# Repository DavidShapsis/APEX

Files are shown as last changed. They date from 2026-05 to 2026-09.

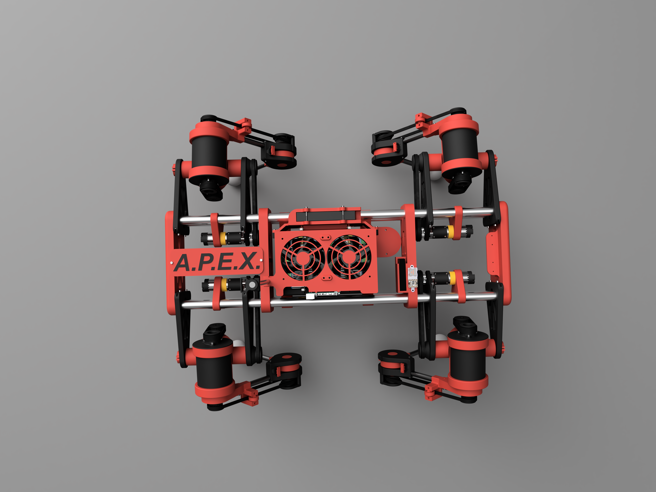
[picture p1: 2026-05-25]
Photos/APEX_top_view.png

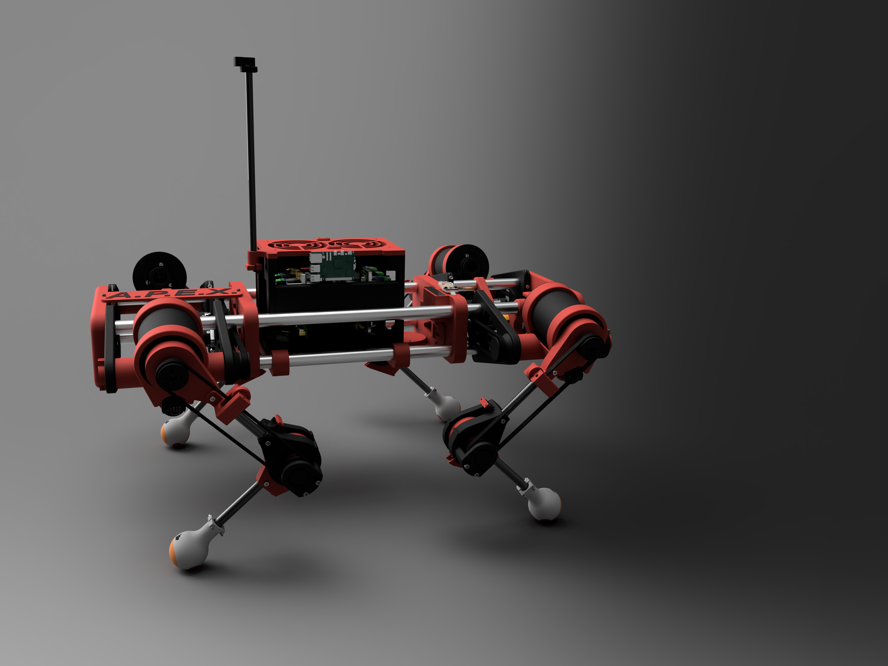
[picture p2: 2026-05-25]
Photos/APEX_side_view.png

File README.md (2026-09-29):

 **⚠️ This is an ongoing project. The code, CAD, and documentation are all actively being developed and are not final.**
 
---
 
# APEX — Autonomous Precision Exploration
 
A fully custom-built quadruped robot dog designed and coded from scratch.

APEX is designed to walk across varied outdoor terrain using real-time inverse kinematics, stay balanced using an IMU, navigate to GPS waypoints autonomously, and stream live camera footage back to any device over WiFi. The long-term goal is onboard ML-based obstacle avoidance for fully autonomous terrain exploration.
 




 
---
 
## Features
 
- **Inverse Kinematics** — custom 3-link IK engine with forward kinematics for recovery, computing joint angles in real time for all four legs
- **Body-Twist Steering** — each foot arcs about the body centre so the robot yaws in place or blends yaw with forward travel into an arc, recruiting the hip-roll joint into the turn (not tank-style stride differencing)
- **IMU Stabilization** — BNO085 quaternion-based roll/pitch feeds a per-leg differential foot-height correction, so the body actually levels instead of just translating
- **GPS Navigation** — autonomous waypoint following using bearing and distance calculations from a HGLRC M100 GPS module; the route is entered and reordered live from the dashboard, and the robot holds position (marching in place) once the last point is reached
- **Live Video Streaming** — USB webcam feed served over Flask to any device on the same network
- **Mission Control Dashboard** — Flask web UI that walks through homing each leg, standing, and going before the robot is allowed to walk; live camera feed with a steering readout, an obstacle-avoidance toggle, and per-leg debug controls. Served entirely from the Pi (Bootstrap vendored locally, no internet needed in the field)
- **ML Obstacle Avoidance** — pretrained monocular depth model (Depth-Anything-V2-Small, ONNX) turns the webcam feed into a forward costmap and steers around obstacles, layered on top of both manual and GPS waypoint steering. Dashboard toggle
- **Threaded Sensor Polling** — every blocking sensor read (IMU + compass over I2C, GPS UART, INA219) runs on its own poller thread; the control loop only ever reads a lock-protected snapshot, so a stuck bus degrades to a safe default instead of stalling the gait
- **Per-Motor Current Sensing** *(planned, not started)* — reading each BTS7960's built-in `IS` output so a joint meeting unexpected resistance (a crash, a jam) drops the robot into its recovery routine, replacing the FSR-based foot contact. No code for this exists yet; see `ENGINEERING_NOTES.md`
- **ROS 2 Integration** — inter-node communication via ROS 2 topics for direction commands, navigation mode switching, and the homing/stand/go/stop dashboard controls

---
 
## BOM
 
| Component | Qty | Notes |
|---|---|---|
| Raspberry Pi 5 | 1 | Main brain |
| Raspberry Pi Pico (RP2040) | 4 | One per leg, runs MicroPython |
| GoBilda 5302 Yellow Jacket Motor (99.5:1, 60 RPM) | 12 | 3 per leg |
| BTS7960 43A H-Bridge | 12 | One per joint |
| BNO085 IMU | 1 | Quaternion-based orientation |
| HGLRC M100-5883 GPS/Compass | 1 | Outdoor autonomous nav |
| INA219 Voltage Monitor | 1 | Battery voltage; current sensing wired but unconfirmed/unused, see `ENGINEERING_NOTES.md` |
| Carbon Fiber Tube (16x12mm) | — | Lower leg structure |
| Aluminum 6063 Tube (1in OD) | — | Upper leg structure |
| 3S 11.1V LiPo 80C 5Ah | 1 | Motor power |
| 2S 7.6V LiHV 3.5Ah | 1 | Electronics power |
| Custom PCB | 1 | High-current motor control, in progress |
 *BOM subject to change. For the most recent BOM go to [APEX BOM on Google Sheets](https://docs.google.com/spreadsheets/d/1m-T2-i6hj74-5jb7eDYWLMdHvXfgs2ABYw7gbwLl6ZI/edit?usp=sharing)*
---
 
## Software Architecture
 
```
Pi 5 (ROS 2)
├── pi5_main.py          # Main control loop, gait generation, homing/stand/go/stop state
├── inverse_kinematics/
│   ├── ik_and_gait.py   # IK, FK, GaitPath, GaitIK, RecoveryPath, shared leg/body geometry
│   └── quadruped_sim.py # PC-only 4-leg gait simulator (no ROS) -- --report and 3D animation modes
├── sensor_hub.py        # Per-sensor poller threads -- keeps blocking I2C/UART off the control loop
├── boot_display.py      # Optional SH1106 OLED: boot progress + status (no-op if absent)
├── imu.py               # BNO085 quaternion → roll/pitch
├── navigation.py        # GPS parsing, compass, waypoint navigation
├── stream_server.py     # Flask dashboard node -- ROS wiring, routes, /status plumbing
├── dashboard_page.py    # The dashboard HTML/CSS/JS (shared string, zero deps)
├── dashboard_preview.py # Throwaway standalone dashboard mock (Flask only, no hardware)
├── static/              # Vendored assets served at /static/ (bootstrap.min.css)
├── webcam.py            # USB camera capture
├── vision_obstacle.py   # Depth model, obstacle costmap, committed avoidance planner
├── vision_test/         # Standalone notebook for tuning the vision pipeline
├── power_monitor.py     # INA219 -- voltage only is read; current/power path unconfirmed, see ENGINEERING_NOTES
├── audio.py             # Bluetooth speaker alerts
├── requirements.txt     # pip dependencies (ROS 2 itself is a separate apt install)
└── single_leg_test.py   # Standalone single-leg test harness (no ROS/IMU/GPS)
 
Pico (MicroPython, x4)
├── pico_main.py         # UART receiver, gait buffer, PID execution loop, homing/stop commands
├── motor_control.py     # BTS7960 PID joint controller with encoder feedback
└── fsr.py               # Force sensitive resistor foot contact (set FSR_PIN per leg)
```
 
### Pi to Pico Protocol
 
The Pi sends gait data over UART to each Pico using a binary protocol:
 
- **Start:** `0xAA 0xAA`
- **Home leg:** `0xAB 0xAB` -- zero this leg's encoders to the current physical pose, no payload
- **Stop leg:** `0xAC 0xAC` -- cut motor holding torque, keep encoder tracking, no payload
- **Payload:** up to 20 steps (gait) or 40 (ramp) x 16 bytes each (`struct.pack('ffff', roll, pitch, knee, is_swing)`)
- **End (cycle):** `0xFF × 16` -- Pico loops the buffer indefinitely (the walking gait)
- **End (one-shot):** `0xFE × 16` -- Pico holds the final step (startup/recovery ramps)
 
Each Pico steps through the gait buffer at 40ms per step. It's a **crawl gait, one leg airborne at a time** (25% swing / 75% stance duty factor) rather than a trot -- the four legs are phase-offset by `[0, N/2, 3N/4, N/4]`, giving lift order FL → RR → FR → RL, with three feet always planted. Each Pico also announces `LEG,<id>` over UART until it's identified, and reports `HOMED,<id>` / `ABORTED,<angles>` asynchronously.
 
---
 
## Kinematics
 
The IK engine uses a 3-link chain (hip abductor, thigh, shin) solving for roll, pitch, and knee angles given a target foot position in (X, Y, Z):
 
1. **Roll** — solved in the X-Z plane using `atan2` + `acos` geometry on the abductor link
2. **Pitch/Knee** — solved in the virtual leg plane using law of cosines
Forward kinematics is used for the recovery path, reconstructing foot position from joint angles to interpolate back to home stance.
 
Segment lengths (cm): `a = 9.65` (abductor), `b = 26.84` (thigh), `c = 24.37` (shin)
 
---
 
## Gait
 
The gait path is a 20-step cycle, one leg airborne at a time (25% of the cycle) so three feet are always planted:
 
- **Swing phase** (first 25% of the cycle): a true half-ellipse -- the foot sweeps forward and up together as matched cos/sin of the same angle, easing into liftoff and touchdown instead of slamming into them
- **Stance phase** (remaining 75%): the foot travels backward at constant velocity (deliberately linear, not elliptical, so all three planted feet move at the same rate and don't scrub against the ground)
- **Body shift**: the body leans toward the diagonally-opposite hip just before each lift, to keep the centre of mass off the edge of the support triangle (ramped from 2 cm to 4 cm as a turn tightens)
- **IMU levelling**: differential per-leg foot-height correction from roll/pitch, not a common offset
 
### Steering
 
A **body twist**, not stride differencing. `build_gait()` takes a forward stride and a yaw-per-cycle; each planted foot arcs about the body centre (`body_twist_xy_path`), its neutral hip position rotated `± yaw/2` across the stroke, so the four feet phased together rotate the body -- the hip-roll joint carrying the lateral part of each arc. `yaw == 0` is the straight gait, unchanged term for term.
 
`pi5_main` maps the turn command (+ = right; a dashboard control or the GPS heading error) to a yaw rate plus a forward stride that tapers to zero by 90°, so a ±90° command spins in place while a smaller heading error arcs and still advances. On the dashboard the **LEFT / RIGHT** buttons send ±45° (a moderate arc at about half stride) and the slider spans the full −90°…+90°, its ends being a spin in place; the slider tracks the buttons so it always shows the active command. `quadruped_sim.py --report` checks the straight gait *and* a turn sweep: a full spin is ~13°/cycle (~16°/s, a 90° turn in ~5.5 s) with the stability margin, joint rate, and one-leg-airborne crawl all holding.
 
Before any of this runs, the robot must be homed, stood up, and started from the web dashboard -- see `ENGINEERING_NOTES.md` for that flow.
 
---
 
## Control Loop
 
`pi5_main.py` runs a ~100 Hz loop that fuses heading, chooses a steering command (manual, GPS, or the avoidance override), and rebuilds the gait only when the command or attitude actually changes. Everything that could block it is pushed onto its own thread:
 
| Thread | Job |
|---|---|
| Control loop | Steering decision, gait rebuild, Pico ack/recovery handling, status publish |
| Gait serial worker | The single writer to the four Pico UARTs -- gait frames, home/stop commands, recovery |
| `SensorHub` pollers | One each for IMU (50 Hz), GPS + compass (10 Hz), INA219 (1 Hz) |
| Vision worker | Depth inference + costmap, 1-3 fps; not started if the ONNX model isn't installed |
| Flask / ROS executor | Dashboard requests and ROS 2 callbacks |
 
The sensor split matters: those reads are synchronous I2C/UART transactions, and a NAKing or wedged bus blocks the kernel for its timeout. Inline, that used to stall steering and the IMU reflex with it. Now each poller owns its device and publishes a timestamped snapshot; the loop reads the snapshot with a staleness cutoff, so a dead sensor degrades to a safe default (flat attitude, hold last heading, skip the battery check) and a watchdog logs which poller is stuck. `python3 sensor_hub.py` runs a self-test with fake sensors, including a hung-bus case.

The compass reads *true* north — `MAGNETIC_DECLINATION_DEG` in `pi5_main.py` (currently `-13` for northern NJ; change it for your area) is added to every heading, and the reading is tilt-compensated with the live IMU attitude so it doesn't wobble with each stride. Bad samples (I2C error, magnetic overflow, dead chip) return `None`; a compass that stops reading for more than 3 s makes the robot hold position under GPS nav rather than drive on a frozen bearing, and lights the degraded banner. It is **not** hard/soft-iron calibrated — absolute accuracy near the motors is poor, but the nav loop re-derives the bearing from GPS every pass so it still converges.

The GPS is guarded the same way: `GPSReader` timestamps its last positional fix, and a receiver that goes quiet (fix older than 5 s) counts as *no fix* even though `has_fix` is still latched — autonomous nav then holds position instead of driving toward a frozen waypoint bearing. A camera that fails to open raises at boot (marked down, degrade banner) rather than reading as healthy while returning nothing.

The INA219 is read for **voltage only** right now — whether a shunt is actually in the load path for current sensing is unconfirmed, so `get_current()`/`get_power()` are kept but unused rather than feeding a meaningless number into the low-battery alarm. `LOW_VOLT_THRESHOLD` in `pi5_main.py` also needs a bench check (see `ENGINEERING_NOTES.md`) to confirm which rail it's actually measuring.
 
---
 
## Obstacle Avoidance
 
Camera-only, using a **pretrained** monocular depth model (Depth-Anything-V2-Small, ONNX) — nothing is trained here. Each frame becomes a relative depth map; a band in front of the feet is sliced into 9 angular bins, and each bin is scored by how much of it reads **nearer than the ground does at that image row**. The planner then takes whatever direction the robot wants to travel and returns the nearest one that is actually passable.
 
That row-relative comparison is the important detail. On flat ground the distance to the ground at image row `r` goes as `1/(r - horizon)`, so depth ramps smoothly from far at the top of the frame to near at the bottom — a single absolute threshold flags the ground itself as an obstacle. An upright object instead occupies rows that would otherwise show ground far away, so it stands out sharply against its own row. A uniform slope shifts a whole row together and is correctly ignored.
 
It runs on its own worker thread at 1–3 fps on the Pi 5 CPU, which is ample — the crawl gait only moves at ~16.7 cm/s. No AI accelerator needed.
 
The planner is a committed state machine, not a per-frame reaction:
 
| State | Behaviour |
|---|---|
| `CLEAR` | Corridor open. Navigation steers, full stride |
| `AVOIDING` | Obstacle ahead. Committed to one side, steering to the passable heading nearest the goal, 0.6x stride |
| `CLEARING` | Corridor reopened. Keeps turning while the obstacle is still in frame, then drives straight until the body is past |
| `BLOCKED` | No gap anywhere. Stride drops to zero — the robot **marches in place**, still standing (unlike STOP, which cuts torque) |
| `ESCAPE` | Still blocked. Slow committed arc toward the least-obstructed side |
 
**Why commitment matters:** the naive version oscillates. Steer away from an obstacle, it leaves the field of view, GPS points straight back at it, repeat forever. Latching a side until the detour completes is what prevents that.
 
**Getting back on track is automatic** — `Navigator.calculate_nav` recomputes the bearing from the live GPS fix every pass, so there is no route line to rejoin. Within a detour the planner always picks the passable heading *closest to the goal bearing*, so it drifts back toward the waypoint as soon as the geometry allows.
 
Verified in simulation against the real `Navigator`: obstacles struck by 0.95 m with avoidance off were cleared by 0.25–0.50 m with it on, with zero steering oscillations, at a 3–19% cost in route time.
 
```bash
cd Code/Pi5
python3 vision_obstacle.py --download    # fetch the ~100MB depth model, once
python3 vision_obstacle.py               # planner self-test, no camera needed
python3 vision_obstacle.py --live 0      # live decisions from the camera
```
 
Then toggle **AVOIDANCE** on the dashboard. While it is on, the video feed is overlaid with the detection bins (red = blocked), so the thresholds can be tuned by eye. `Code/Pi5/vision_test/obstacle_avoidance_test.ipynb` is a standalone notebook for the same tuning against still images.
 
**Not yet verified on hardware** — see `ENGINEERING_NOTES.md` for what needs measuring first.
 
---
 
## Dashboard
 
Open `http://<pi-ip>:5000`. Top to bottom: live camera feed, **Steering** (direction readout, LEFT / FWD / RIGHT, the −90…+90 slider), **Startup** (Home ×4 → STAND → GO → STOP), **Navigation** (collapsible GPS routing + obstacle avoidance), then **Debug** per-leg deactivation at the bottom. Each card's wordy explanation is tucked behind a small **i** button. STAND and GO stay disabled, with a warning banner, until all four legs are homed; status pills up top show homed count / standing / walking.
 
The **Navigation** card holds two collapsible sections, both closed on load. *GPS Waypoints & Routing* has the NAV MODE master toggle, a waypoint editor (one latitude box and one longitude box per point — paste a Google Maps "lat, lng" coordinate string into either box and it splits across both — ▲/▼ to reorder, × to remove, **+ Add point**, **Send route** — nothing reaches the robot until pressed), and a **Start / Pause / Stop** transport row greyed out by state: Start runs the route from the first point, Pause holds position without advancing, Stop returns to manual and rewinds. NAV MODE and Start are refused until at least one waypoint has been sent — the toggle greys out and reads *add a waypoint first* — and the controller rejects the switch to autonomous the same way, so a lost or spoofed message can't put the robot in nav mode with nowhere to go. On reaching the last point the robot holds position. *Obstacle Avoidance* has the avoidance toggle and its live state readout.
 
The markup lives in one place — `dashboard_page.py`, a plain string with no imports — so `stream_server.py` (the real node) and `dashboard_preview.py` (a hardware-free mock for working on the UI) render the identical page. Styling is an APEX red/black theme over Bootstrap 5, and Bootstrap is **vendored** at `Code/Pi5/static/bootstrap.min.css` rather than pulled from a CDN, so the page is fully functional when the Pi is its own access point with no route to the internet.
 
---
 
## Getting Started
 
> Full setup instructions are a work in progress. The notes below are enough to get running.
 
### Pi 5 Requirements
 
```bash
pip install -r Code/Pi5/requirements.txt
```

`onnxruntime` / `numpy` (obstacle avoidance) and `luma.oled` (boot OLED) are in
there but optional — the code runs without them. ROS 2 (Humble or later) is a
separate apt install and is only needed for `pi5_main.py`.

Obstacle avoidance is optional at runtime — if `onnxruntime` or the model file is missing, the import is caught, the dashboard shows `AVOIDANCE: NO MODEL`, and everything else runs unchanged.

Hardware init is non-fatal: a missing IMU, dead GPS, unplugged camera or absent power monitor each leave that subsystem reporting *down* — an amber "running degraded" banner on the dashboard, and a line on the optional SH1106 OLED (`boot_display.py`, wired per `HARDWARE.md`) — rather than stopping the boot. Only the Flask dashboard itself is required. `pip install luma.oled` enables the OLED; without it the same progress goes to stdout.
 
ROS 2 (Humble or later) required for `pi5_main.py`. For testing without ROS, use `single_leg_test.py` — it has no ROS dependency, runs a single leg, and serves the camera stream.
 
### Running the single-leg test
 
```bash
cd Code/Pi5
python3 single_leg_test.py
```
 
Then open `http://<pi-ip>:5000` in a browser for the control panel and live camera feed.
 
### Running full production
 
```bash
cd Code/Pi5
source /opt/ros/humble/setup.bash
python3 pi5_main.py
```
 
### Pico Firmware
 
Flash each Pico with MicroPython, then copy the contents of `Code/Pico/` to the Pico filesystem. The main loop starts automatically on boot. **The legs do not move on their own** -- each Pico just holds its power-on position under light PID until it's homed. From the web dashboard: home each leg individually, then **Stand**, then **Go**. A **Stop** control cuts motor power without losing homing.
 
### ⚠ Before powering the motors
 
- **Re-flash all four Picos.** Seven firmware fixes live on the Pico side; a Pi running current code against old firmware still cannot stand, and still will not walk. See the banner in `ENGINEERING_NOTES.md`.
- **Set `FSR_PIN` in `pico_main.py`** to whichever pin carries that leg's own foot sensor before you connect the FSRs. It defaults to `16`.
- **Set `LEG_ID`** on each board — all four currently ship as `0`.
- **Check the IMU roll/pitch signs on a stand.** Levelling assumes right-side-down is positive roll and nose-up is positive pitch. If either axis is bolted in backwards the correction is positive feedback and will drive the robot over. Steps are in `ENGINEERING_NOTES.md` → *Before you walk it*.
 
A jammed joint is now caught in software: `JointController` latches a stall when the PID has been saturated for 1.5 s with neither the error falling nor the encoder turning, zeroes that joint's PWM, and raises the existing `ABORTED` path so the Pi runs its recovery. Before this the joint simply held 100% duty until something burned out.
 
---
 
## Project Status
 
| Component | Status |
|---|---|
| IK / FK engine | Complete |
| Gait generation | Complete |
| Pico PID motor control | Complete |
| Pi-Pico serial protocol | Complete — frames stage on the Pico, re-sends rate-limited to 10 Hz |
| IMU stabilization | Complete — **verify the roll/pitch signs on a stand first** |
| GPS navigation | Complete |
| Camera streaming | Complete |
| Recovery path | Complete |
| Homing / Stand / Go / Stop dashboard workflow | Complete |
| ML obstacle avoidance | Built, needs hardware tuning |
| Motor stall protection (software) | Complete — error *and* encoder must both stall; needs a bench check |
| Per-motor current sensing (BTS7960 `IS`) | Planned, not started |
| FSR foot contact | Complete — set `FSR_PIN` to match your wiring |
| Mechanical build | In progress |
| Custom PCB | In progress |
| CAD files | In progress |
 
---
 
## Repo Structure
 
```
Code/
├── Pi5/                 # Raspberry Pi 5 code
└── Pico/                # RP2040 MicroPython firmware
```
 
---
 
## License
 
MIT
 
---

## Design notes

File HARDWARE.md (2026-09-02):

# APEX — Pi 5 pin allocation & the status OLED

Where every wire on the Raspberry Pi 5 40‑pin header goes, and how to add the
1.3" SH1106 OLED that `Code/Pi5/boot_display.py` drives.

> The OLED is **optional**. `boot_display.py` degrades to stdout if the panel or
> the `luma.oled` library is missing, so nothing here is required to run the
> robot — it just means a boot failure is visible without a laptop on the
> serial console.

---

## The screen

**Hosyond / generic 1.3" I2C OLED, 128×64, SH1106 controller.** 4‑pin module,
markings usually `GND VCC SCL SDA`.

- Controller is **SH1106**, *not* SSD1306. The SSD1306 driver runs but leaves a
  ~2‑pixel column offset — use the SH1106 driver (`luma.oled`'s `sh1106` class
  handles the 132‑vs‑128 column RAM offset for you).
- I2C address **0x3C** (fixed on these modules; a few are 0x3D).
- 3–5 V input, 3.3 V logic — power it from **3.3 V** so the SDA/SCL lines stay
  at the Pi's 3.3 V level.

Install the driver on the Pi:

```bash
pip install luma.oled        # pulls in luma.core + pillow
```

---

## What's already used on the header

Derived from the code (`CompassReader`, `INA219`, `IMU`, `pi5_main.pico_ports`).
Buses other than I2C1 and UART0 are enabled by `dtoverlay=` lines you added to
`/boot/firmware/config.txt` — check that file for the exact GPIOs if anything
below doesn't match your board.

| Bus / signal | Device | Addr | Header pins (BCM GPIO) | Notes |
|---|---|---|---|---|
| **I2C1** | QMC5883 compass | `0x0D` | 3 (GPIO2 SDA), 5 (GPIO3 SCL) | The Pi's primary I2C. Always enabled via `dtparam=i2c_arm=on`. |
| **I2C3** (`/dev/i2c-3`) | INA219 power monitor | `0x40` | GPIO4 / GPIO5 by default on Pi 5 (`dtoverlay=i2c3`) — **verify in config.txt** | |
| **I2C‑13** (`/dev/i2c-13`) | BNO085 IMU | `0x4A`/`0x4B` | non‑standard bus you enabled — **check config.txt** | `IMU(bus_id=13)`; the `sda_pin`/`scl_pin` args are unused on this path |
| **UART0** (`/dev/ttyAMA0`) | Leg Pico #0 | — | 8 (GPIO14 TX), 10 (GPIO15 RX) | |
| **UART2/3/4** (`ttyAMA2‑4`) | Leg Picos #1‑3 | — | per your `dtoverlay=uart2/3/4` lines — **check config.txt** | Pi 5 defaults: uart2 = GPIO4/5, uart3 = GPIO8/9, uart4 = GPIO12/13 |
| Power | — | — | 1 or 17 (3.3 V), 2 or 4 (5 V) | |
| Ground | — | — | 6, 9, 14, 20, 25, 30, 34, 39 | |

Nothing else in the code touches GPIO directly (motors and encoders are on the
Picos, not the Pi).

**No I2C device currently answers at 0x3C**, so the OLED can share any of the
I2C buses above without an address clash.

---

## Recommended wiring — hang it on I2C1 with the compass

I2C is a bus: extra devices wire **in parallel** on the same two lines. Putting
the OLED on **I2C1** (pins 3 & 5) needs **zero config changes** — that bus is
already up and proven by the compass — and 0x3C ≠ 0x0D, so they coexist.

| OLED pin | → Pi 5 header pin | Signal |
|---|---|---|
| `VCC` | **1** | 3.3 V |
| `GND` | **9** | GND |
| `SCL` | **5** | GPIO3 / SCL1 |
| `SDA` | **3** | GPIO2 / SDA1 |

```
        Pi 5 header (top-left corner)
        ┌───────────────────────
   3V3  │ 1 ●  ● 2   5V
   SDA1 │ 3 ●  ● 4   5V
   SCL1 │ 5 ●  ● 6   GND
        │ 7 ●  ● 8
   GND  │ 9 ●  ● 10
        └───────────────────────
   OLED:  VCC→1   SDA→3   SCL→5   GND→9
```

Pins 3 and 5 already carry the compass. If the compass is on a breakout with
pass‑through pads, tap those. Otherwise use a 2‑into‑1 Dupont splitter or solder
both leads to pins 3/5.

Then in `Code/Pi5/boot_display.py` the default `BootDisplay(port=1, address=0x3C)`
is already correct — nothing to change.

### Verify

```bash
sudo apt install -y i2c-tools      # once
i2cdetect -y 1
```

Expect `0d` (compass) **and** `3c` (OLED):

```
     0  1  2  3  4  5  6  7  8  9  a  b  c  d  e  f
00:                         -- -- -- -- 0d -- --
30: -- -- -- -- -- -- -- -- -- -- -- -- 3c -- -- --
40: 40 -- -- -- ...
```

Then:

```bash
python3 Code/Pi5/boot_display.py     # marches a fake boot sequence across the panel
```

---

## Alternative — a dedicated bus (electrical isolation from the compass)

If you'd rather the OLED not share the compass bus (a wedged OLED could add
`Remote I/O error`s to compass reads — `SensorHub` already tolerates those by
holding the last heading, but still), add a software I2C bus on two free pins.
Append to `/boot/firmware/config.txt`:

```
dtoverlay=i2c-gpio,bus=7,i2c_gpio_sda=16,i2c_gpio_scl=26
```

That puts a new `/dev/i2c-7` on **GPIO16 (pin 36)** and **GPIO26 (pin 37)** —
both unused above, but confirm against your own config.txt first. Reboot, then:

```python
BootDisplay(port=7, address=0x3C)   # in pi5_main.main()
```

Wiring becomes VCC→pin 1, GND→pin 34, SDA→pin 36, SCL→pin 37.

---

## Troubleshooting

| Symptom | Cause |
|---|---|
| `i2cdetect` shows nothing at 0x3C | power/ground swapped, or SDA/SCL swapped; some clones need a moment after power‑on |
| Panel lights but shows garbage / shifted 2 px | SSD1306 driver in use — must be **SH1106** |
| `[OLED] not available (No module named 'luma')` | `pip install luma.oled` on the Pi |
| Works standalone, blank when `pi5_main` runs | address or port wrong in `BootDisplay(...)`, or another process holds the bus |
| Compass reads get flaky after adding the OLED | move the OLED to a dedicated bus (section above) |

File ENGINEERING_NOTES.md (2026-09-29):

# Engineering Notes

Defects found during a full read of the control path that were **not** fixed, with
why they were deferred, plus the manual configuration steps the fixes introduced.
Ordered by how badly they bite. Fixed defects are kept here too, marked
**RESOLVED**, as a record of what broke and why the fix works — see git history
for the actual diffs.

## Read this first

The two-minute version. Full detail is one click away on each line.

- **[IMU roll/pitch signs are unverified](#imu-banner)** — if either axis reads
  backwards, self-levelling pushes the tilt *further* over instead of correcting
  it. [Bench-check it](#verify-the-imu-roll-pitch-signs-do-this-one-first) before
  the first unsupported walk — do this one first.
- **[Re-flash all 4 Picos](#reflash-banner)** — seven firmware fixes are sitting
  in `Code/Pico/` and none of them exist on the robot until it's reflashed.
- **[Set `LEG_ID` on each Pico](#set-leg-id-on-each-pico)** — all four boards
  currently ship as `0`.
- **[Set `FSR_PIN` before wiring the foot sensors](#resolved-fsr-abort-fired-on-the-first-swing-step-of-every-leg)** — defaults to 16, must match each leg's actual wiring.
- **[Verify the `reverse` flags during an actual turn](#set-the-left-right-reverse-flags-now-matters-for-turning-verify-it)** — wrong polarity here now steers the wrong way, not just at boot.
- **[PID `kp = 0.8` still needs bench tuning](#pid-kp-still-needs-bench-tuning-windup-ruled-out-kd-fixed)** — simulation favors a softer gain, but the sim has no gravity or load to fight.
- **[Confirm which rail the INA219 is on](#low-voltage-alarm-threshold-may-be-unreachable-check-which-rail-the-ina219-is-on)** — the low-voltage alarm may be watching a rail that never drops.
- **[IK clamps unreachable targets silently](#ik-clamps-unreachable-targets-silently)** — a bad command doesn't error, it just quietly clips.
- **[Obstacle avoidance has never run on real hardware](#obstacle-avoidance-built-and-simulated-never-run-on-hardware)** — simulated and unit-tested only; tune thresholds on the bench first.
- **[Compass hard/soft-iron calibration still isn't done](#compass-declination-tilt-now-handled-hard-soft-iron-calibration-still-not)** — declination and tilt compensation are in, calibration against local magnetic interference is not.
- **[Per-motor current sensing is planned, not built](#current-sensing-banner)** — the BTS7960 `IS` pins could catch a jammed joint or collision; nothing reads them yet.
- **[Idea, not built: one generic preloaded UF2 for all 4 Picos](#planned-ship-one-generic-uf2-with-the-pico-files-preloaded)** — flash MicroPython and the default `.py` files in a single step; still editable in Thonny afterward.
- **[Swing clearance is 4.76 cm, not the nominal 5.0](#swing-clearance-is-4-76-cm-not-the-nominal-5-0)** — small margin, worth knowing before assuming ground clearance.
- **[Encoder zero must match `HOME_POSE`](#encoder-zero-must-match-home-pose-this-is-what-homing-top-of-doc-is-for)** — that's what the manual homing step (below) is for.
- **[Protocol gaps accepted for now](#protocol-gaps-accepted-for-now)** — known wire-protocol rough edges that aren't worth fixing yet.

<details>
<summary><strong>Full section index</strong> (every heading in this document)</summary>

- [RESOLVED — receiving a gait frame froze the gait (the robot would not walk)](#resolved-receiving-a-gait-frame-froze-the-gait-the-robot-would-not-walk)
- [RESOLVED — pressing Go yanked three planted feet sideways](#resolved-pressing-go-yanked-three-planted-feet-sideways)
- [RESOLVED — the Pico threw away every Stand and Go ramp (robot could not stand)](#resolved-the-pico-threw-away-every-stand-and-go-ramp-robot-could-not-stand)
- [RESOLVED — every gait re-send teleported the feet (25.6° / 17.6 cm, full duty)](#resolved-every-gait-re-send-teleported-the-feet-25-6-17-6-cm-full-duty)
- [RESOLVED — STAND while walking commanded a 68.6 cm lurch](#resolved-stand-while-walking-commanded-a-68-6-cm-lurch)
- [RESOLVED — one InverseKinematics shared across threads returned wrong angles](#resolved-one-inversekinematics-shared-across-threads-returned-wrong-angles)
- [Swing clearance is 4.76 cm, not the nominal 5.0](#swing-clearance-is-4-76-cm-not-the-nominal-5-0)
- [Not a defect: stance y quantisation](#not-a-defect-stance-y-quantisation)
- [Obstacle avoidance — built and simulated, never run on hardware](#obstacle-avoidance-built-and-simulated-never-run-on-hardware)
  - [Tune these on the bench before trusting it outdoors](#tune-these-on-the-bench-before-trusting-it-outdoors)
  - [RESOLVED — an absolute depth threshold read the ground as an obstacle](#resolved-an-absolute-depth-threshold-read-the-ground-as-an-obstacle)
  - [Known limits of the approach itself](#known-limits-of-the-approach-itself)
  - [Validated against real ground-robot imagery](#validated-against-real-ground-robot-imagery)
  - [First hardware session should be, in order](#first-hardware-session-should-be-in-order)
- [PLANNED — migrate ground-contact sensing from FSR to current sensing](#planned-migrate-ground-contact-sensing-from-fsr-to-current-sensing)
- [PLANNED — ship one generic UF2 with the Pico files preloaded](#planned-ship-one-generic-uf2-with-the-pico-files-preloaded)
- [Homing — a manual step you have to do, before every power-on](#homing-a-manual-step-you-have-to-do-before-every-power-on)
  - [RESOLVED — Home button, one leg at a time](#resolved-home-button-one-leg-at-a-time)
  - [RESOLVED — boot no longer moves the legs](#resolved-boot-no-longer-moves-the-legs)
  - [RESOLVED — smooth ramps instead of one big jump: Stand and Go](#resolved-smooth-ramps-instead-of-one-big-jump-stand-and-go)
  - [RESOLVED — Stop](#resolved-stop)
  - [Bug caught while building Stand/Go, not previously exercised](#bug-caught-while-building-stand-go-not-previously-exercised)
  - [Still open, and worth deciding before any of this is trusted](#still-open-and-worth-deciding-before-any-of-this-is-trusted)
- [Before you walk it](#before-you-walk-it)
  - [Set LEG_ID on each Pico](#set-leg-id-on-each-pico)
  - [Set the left/right `reverse` flags — now matters for turning, verify it](#set-the-left-right-reverse-flags-now-matters-for-turning-verify-it)
  - [Verify the IMU roll/pitch signs — do this one first](#verify-the-imu-roll-pitch-signs-do-this-one-first)
  - [Front/rear mirroring is handled in software — verified](#front-rear-mirroring-is-handled-in-software-verified)
  - [Body geometry (set — recorded here because it lives nowhere else)](#body-geometry-set-recorded-here-because-it-lives-nowhere-else)
- [Debug tool: per-leg deactivation](#debug-tool-per-leg-deactivation)
- [Will make the robot fall over](#will-make-the-robot-fall-over)
  - [OPEN — the IMU roll/pitch signs are unverified, and a wrong one is positive feedback](#open-the-imu-roll-pitch-signs-are-unverified-and-a-wrong-one-is-positive-feedback)
  - [RESOLVED — body shift, phased with the lift sequence](#resolved-body-shift-phased-with-the-lift-sequence)
  - [RESOLVED — `height2` (stance push) set to 0](#resolved-height2-stance-push-set-to-0)
  - [RESOLVED — `STEP_TICK_MS` raised 20 → 40 ms](#resolved-step-tick-ms-raised-20-40-ms)
- [Will misbehave](#will-misbehave)
  - [RESOLVED — `current_state` conflated operating mode with transient activity](#resolved-current-state-conflated-operating-mode-with-transient-activity)
  - [RESOLVED — one leg recovers while the other three keep walking: policy is "go to neutral"](#resolved-one-leg-recovers-while-the-other-three-keep-walking-policy-is-go-to-neutral)
  - [RESOLVED — steering is now a body twist (yaw), not differential stride](#resolved-steering-is-now-a-body-twist-yaw-not-differential-stride)
  - [RESOLVED — mission end now holds position; route is editable from the dashboard](#resolved-mission-end-now-holds-position-route-is-editable-from-the-dashboard)
  - [RESOLVED — blocking sensor reads moved off the control loop](#resolved-blocking-sensor-reads-moved-off-the-control-loop)
  - [RESOLVED — IMU stabilization is now differential, not a common offset](#resolved-imu-stabilization-is-now-differential-not-a-common-offset)
  - [Low-voltage alarm threshold may be unreachable — check which rail the INA219 is on](#low-voltage-alarm-threshold-may-be-unreachable-check-which-rail-the-ina219-is-on)
  - [RESOLVED — an out-of-range target left the motor at its last duty](#resolved-an-out-of-range-target-left-the-motor-at-its-last-duty)
  - [Compass: declination + tilt now handled; hard/soft-iron calibration still not](#compass-declination-tilt-now-handled-hard-soft-iron-calibration-still-not)
  - [RESOLVED — autonomous nav no longer drives on a dead sensor](#resolved-autonomous-nav-no-longer-drives-on-a-dead-sensor)
  - [RESOLVED — a camera that fails to open no longer reads as healthy](#resolved-a-camera-that-fails-to-open-no-longer-reads-as-healthy)
  - [RESOLVED — `port_by_leg` mutated without the serial lock](#resolved-port-by-leg-mutated-without-the-serial-lock)
  - [INA219 — voltage-only for now; confirm the wiring](#ina219-voltage-only-for-now-confirm-the-wiring)
  - [RESOLVED — two repo files could not run at all](#resolved-two-repo-files-could-not-run-at-all)
  - [RESOLVED — Pico PID state was not reset when drive is cut](#resolved-pico-pid-state-was-not-reset-when-drive-is-cut)
  - [RESOLVED — `fsr.py` interrupt helpers could not both be used](#resolved-fsr-py-interrupt-helpers-could-not-both-be-used)
  - [IK clamps unreachable targets silently](#ik-clamps-unreachable-targets-silently)
  - [RESOLVED — a blocked leg sat at 100% PWM indefinitely (needs a Pico reflash)](#resolved-a-blocked-leg-sat-at-100-pwm-indefinitely-needs-a-pico-reflash)
  - [RESOLVED — FSR abort fired on the FIRST swing step of every leg](#resolved-fsr-abort-fired-on-the-first-swing-step-of-every-leg)
  - [PID: `kp` still needs bench tuning (windup ruled out, `kd` fixed)](#pid-kp-still-needs-bench-tuning-windup-ruled-out-kd-fixed)
  - [Minor: stale target for one tick](#minor-stale-target-for-one-tick)
- [Verify on hardware](#verify-on-hardware)
  - [RESOLVED — BNO085 constant names, and boot no longer dies on a bad hardware init](#resolved-bno085-constant-names-and-boot-no-longer-dies-on-a-bad-hardware-init)
  - [RESOLVED — BTS7960 dual enable confirmed tied together on the PCB](#resolved-bts7960-dual-enable-confirmed-tied-together-on-the-pcb)
  - [Encoder zero must match HOME_POSE — this is what homing (top of doc) is for](#encoder-zero-must-match-home-pose-this-is-what-homing-top-of-doc-is-for)
  - [Dead branch in `imu.py`](#dead-branch-in-imu-py)
- [Structural notes from the full review (no defect, worth knowing)](#structural-notes-from-the-full-review-no-defect-worth-knowing)
  - [The IK cannot flip the knee to the other solution — verified](#the-ik-cannot-flip-the-knee-to-the-other-solution-verified)
  - [Gait quality — one leg up, three legs pushing; turning really does use hip roll](#gait-quality-one-leg-up-three-legs-pushing-turning-really-does-use-hip-roll)
  - [What `reverse` does and does not control](#what-reverse-does-and-does-not-control)
- [Protocol gaps (accepted for now)](#protocol-gaps-accepted-for-now)

</details>

---

> **RE-FLASH THE PICOS BEFORE THE NEXT POWERED TEST.** Seven firmware defects
> have been fixed in `Code/Pico/` and none of them reach the robot until it is
> reflashed — a Pi running the new code against old firmware still cannot stand,
> and still will not walk:
>
> - the Stand and Go ramps were silently discarded (the robot could not stand at all)
> - **receiving a frame froze the gait — measured 0 steps in 20 s at any re-send
>   faster than 69 ms, i.e. the robot stands still while the dashboard says WALKING**
> - the step clock's cadence tracked loop jitter instead of being a fixed 40 ms
> - every gait re-send restarted the cycle from step 0, slamming the feet
> - a blocked joint held 100% PWM forever, with nothing to stop it
> - the FSR abort would have fired on every leg's first swing step
> - PID state survived a Stop, saturating the integrator on resume
>
> Also **set `LEG_ID`** (all four boards currently ship as `0`) and **`FSR_PIN`**
> before wiring the foot sensors. Each is written up in its own section below.

> **VERIFY THE IMU ROLL/PITCH SIGNS BEFORE THE FIRST UNSUPPORTED WALK.** Body
> levelling assumes right-side-down is a positive roll and nose-up a positive
> pitch. Whether the BNO085 actually reads that way depends on how it is bolted
> in, nothing in the code or the simulator can detect it, and if either axis is
> inverted the correction is **positive feedback** — it grows the tilt to 8.6° of
> self-inflicted lean against a 2.4 cm stability margin. Two-minute bench check in
> *Will make the robot fall over → OPEN — the IMU roll/pitch signs are unverified*.

> **TO BUILD: per-motor current sensing off the BTS7960 IS pins.**
> **Not implemented — no code for this exists yet.**
>
> Every BTS7960 already has a built-in current-sense output (`R_IS` / `L_IS`, a
> current mirror at roughly 1/8500 of load current). Feeding those into the Pico
> means each leg can watch what its own three motors are actually drawing, and a
> current spike = **the joint met resistance it shouldn't have** — the robot walked
> into something, a foot jammed, a link is binding. That's the trigger to abort the
> gait and drop into `handle_recovery` instead of grinding the motor against
> whatever stopped it.

**Verify the whole control path without hardware:**

```bash
cd Code/Pi5/inverse_kinematics && python quadruped_sim.py --report   # gait verdict
cd Code/Pi5 && python vision_obstacle.py                             # avoidance planner
cd Code/Pi5 && python sensor_hub.py                                  # sensor pollers
```

**Verify the gait before touching hardware:**

```bash
cd Code/Pi5/inverse_kinematics
python quadruped_sim.py --report      # numeric verdict, no dependencies
python quadruped_sim.py               # 3D animation, needs matplotlib
```

`matplotlib` is not currently installed (`pip install matplotlib`), which also means
`gait_testing2.py` and `gait_testing3.py` cannot run as-is. `--report` works without
it.

---

## RESOLVED — receiving a gait frame froze the gait (the robot would not walk)

**The worst defect found so far. It stopped the robot walking at all, silently.**
Needs a Pico reflash *and* the Pi-side change.

A gait frame is `2 + 20*16 + 16 = 338` bytes; at 115200 8N1 that is **29.3 ms of
wire time** per port. Two things then conspired on the Pico:

1. `gait_buffer` was cleared at `START_MARKER` and refilled in place, and step 3
   was gated on `not is_receiving` — so for the whole 29.3 ms the leg had nothing
   to step through and simply held its last target;
2. `last_step_time` was reset to *now* on **every** end marker, restarting the
   40 ms tick from zero each time a frame landed.

So a frame had to arrive, and then a further 40 ms of silence had to pass, before
the gait advanced by one step. The Pi's re-send trigger (steering moved >5°, tilt
>1.5°, stride >0.05) is evaluated every ~10 ms and **nothing rate-limited it** —
during a turn, or on any ground that moves the IMU, the Pi re-sent far faster than
that. Measured in `wire_timing.py`, replaying the real parser logic against real
baud timing:

| Pi re-sends every | gait steps in 20 s | vs. commanded |
|---|---|---|
| 20 ms | **0** | 0% — *and frames truncated mid-flight* |
| 50 ms | **0** | 0% |
| 69 ms | **0** | 0% |
| 100 ms | 200 | 40% |
| 250 ms | 400 | 80% |
| never | 499 | 100% |

Below ~30 ms it got worse still: the worker's own send loop is ~22 ms against
29.3 ms of wire time, so it began the next frame while the previous was still
draining and `reset_output_buffer()` — `tcflush(TCOFLUSH)` on POSIX — **discarded
the tail**, end marker included. The Pico then sat in `is_receiving` forever,
eating the next `START_MARKER` as payload, until enough garbage arrived to trip
`MAX_GAIT_STEPS`.

Three fixes, and the gait now runs at 498–499 steps / 20 s at *every* re-send rate:

- **Pico — staging buffer.** Frames land in `rx_buffer` and are swapped into
  `gait_buffer` only once their end marker is parsed. Step 3 lost its
  `not is_receiving` condition, so the leg keeps walking the last complete cycle
  while the next one is on the wire. A truncated or desynced frame now discards
  only the staged copy, so it can no longer freeze a leg either.
- **Pico — `RESYNC_INTERVAL_MS = 5000`.** The step clock is re-aligned to a frame
  boundary at most every 5 s instead of on every frame. Between re-syncs the
  boards free-run on their crystals: at a worst-case 100 ppm spread that is 0.5 ms
  of drift over 5 s, against a 40 ms tick and the one-tick guard band between each
  leg's swing window. Cost is at most one truncated tick per 5 s, under 1% of
  walking speed. A genuinely new trajectory (ramp, recovery, a cycle of a
  different length) still re-syncs immediately, which is the moment it matters.
- **Pi — `MIN_GAIT_RESEND_S = 0.10` and `_drain()`.** The control loop will not
  push frames faster than 10 Hz, and the worker now `flush()`es each port before
  the next `reset_output_buffer()` can run, which makes the truncation race
  impossible rather than merely unlikely. Skipping a re-send loses nothing:
  `last_sent_*` is only updated when a frame actually goes out, so the delta stays
  tripped and the update leaves on the next eligible pass.

Also fixed alongside: the tick advanced by `last_step_time = ticks_ms()`, making
the real cadence 40 ms *plus* however long that pass took. Harmless while every
end marker re-synced the clock; not harmless once re-syncs are 5 s apart. It now
advances by exactly `STEP_TICK_MS`, snapping forward only if it has fallen more
than a full tick behind.

---

## RESOLVED — pressing Go yanked three planted feet sideways

`engage_walking()` ramped every leg from the stand pose to `all_angles[0]`, then
started the cyclic walk. But `_gait_serial_worker` rotates each leg's buffer by
`phase_offsets()` — buffer index `j` for leg L is global tick `j - offset_L`,
which is exactly what `apply_body_shift()` assumes — so leg L's first *commanded*
frame is `all_angles[offsets[L]][L]`, not `all_angles[0][L]`.

Ramping all four to index 0 put them at four different points of the cycle at
once, a configuration the body never actually holds, and the first cyclic tick
then snapped each leg to its real phase:

| leg | phase offset | joint jump | foot moved | in one 40 ms tick |
|---|---|---|---|---|
| Front-Left | 0 | 0.00° | 0.00 cm | correct by luck — its offset is 0 |
| Front-Right | 10 | 10.95° | 7.11 cm | |
| Rear-Right | 15 | 11.42° | 6.93 cm | |
| Rear-Left | 5 | **21.45°** | **13.15 cm** | |

Normal stance travel is 0.67 cm per tick and the joint-rate budget behind
`STEP_TICK_MS = 40` is 9.4°/tick, so this was ~20× over on both counts. All four
feet are planted at that instant (swing is local indices 1–4, not 0), so nothing
was airborne to absorb it — the three legs fought each other through the frame at
full duty, either scrubbing the feet or lurching the body. This is precisely the
slam the whole Home → Stand → Go sequence exists to prevent, and it fired on the
first walking command every single time.

`gait_entry_pose()` now returns each leg's own phase-shifted entry frame and the
ramp targets that. Verified: worst residual jump 0.00°, and the first cyclic tick
is 9.26° — inside budget.

---

## RESOLVED — the Pico threw away every Stand and Go ramp (robot could not stand)

**This one stopped the robot working at all, and needs a Pico reflash to fix.**

`pico_main.MAX_GAIT_STEPS` was **32**. It exists as a desync guard — an overlong
frame means the byte stream lost sync mid-payload, and the cap stops the buffer
growing until `MemoryError`:

```python
gait_buffer.append(parts)
if len(gait_buffer) > MAX_GAIT_STEPS:
    gait_buffer = []          # the WHOLE frame is thrown away
    is_receiving = False
```

But the largest frame the Pi legitimately sends is the Stand/Go Cartesian ramp,
and `build_ramp(steps=40)` → `cartesian_ramp` → `range(steps + 1)` = **41
frames**. Every STAND and every GO therefore hit the guard at frame 33, had the
whole buffer discarded, and the remaining 8 frames plus the end marker were
rescanned as raw bytes looking for a start marker. The leg never left its homed
pose. Nothing logged it — from the Pi's side the frame went out fine.

The 20-frame walking gait, the 21-frame recovery path and the 2-frame
`settle_to_stand` were all under the cap, which is why the bug hid: everything
except the two ramps worked.

**Fixed** by raising `MAX_GAIT_STEPS` to **48** (still a desync guard, now above
every legitimate frame) and adding `PICO_MAX_FRAMES = 48` on the Pi, which
`send_entire_gait()` checks — it now logs and returns `False` rather than
believing an oversized frame was sent, and `request_stand` / `engage_walking` /
`settle_to_stand` propagate that failure instead of setting `standing = True`
regardless. Verified by replaying the real wire bytes through a copy of the
Pico's parser: the 41-frame ramp is accepted and ends holding the stand pose.

---

## RESOLVED — every gait re-send teleported the feet (25.6° / 17.6 cm, full duty)

Also needs the Pico reflash. The Pi rebuilds and re-sends the entire gait
whenever the steering command moves >5°, the IMU tilt moves >1.5°, or the
avoidance stride changes — which in normal walking is often. The Pico's
end-marker handler did:

```python
current_step_index = 0      # restart the cycle
```

So a foot that was mid-stance was told, in one 40 ms tick, to be at the start of
swing instead. That is a phase jump, not a geometry change, and it is large:

| re-send trigger | old (restart at 0) | now (phase kept) |
|---|---|---|
| straight → hard turn | 25.6° / 17.6 cm | **7.1° / 4.2 cm** |
| straight → 45° arc | 20.5° / 12.8 cm | **7.6° / 4.6 cm** |
| walk → march in place | 14.5° / 5.0 cm | **8.9° / 5.0 cm** |
| IMU tilt nudge only | 21.5° / 13.1 cm | **0.0° / 0.00 cm** |

At `kp = 0.8` (saturating above 1.25°) all of the left column is a full-duty slam
— the same failure class as the STAND lurch below, but happening several times a
second while walking rather than once on a button press.

**Fixed** by keeping the buffer index across a re-send *of the same walking
cycle* — same length, both cyclic — and resetting to 0 only for a genuinely new
trajectory (a one-shot ramp, or a cycle of a different length, which must run
from its first entry). `last_step_time` is still reset on every frame, which is
worth keeping: all four boards get their end marker within a few ms of each
other, so it re-aligns the 40 ms tick across legs and stops them free-running
apart. Verified in the wire simulation: all four legs keep the same index across
a re-send and exactly one leg is still airborne immediately after.

Note this is also *safer* for phase than the old behaviour. Previously, if one
leg missed a frame, the three that received it reset to 0 while the fourth kept
counting — a real desync. Now a leg that misses a frame simply keeps its place.

---

## RESOLVED — STAND while walking commanded a 68.6 cm lurch

Found during a full-codebase review, not previously exercised. `request_stand()`
always ramped from `HOME_POSE`, and **nothing anywhere refused it while the robot
was walking** — not the dashboard (`standBtn` was gated only on all-legs-homed),
not the `/stand` route, not the controller. Pressing STAND mid-walk therefore
commanded step 0 of a HOME_POSE ramp — roll 90°, knee 180°, legs straight out —
while the legs were actually near the gait pose:

| | roll | pitch | knee | foot |
|---|---|---|---|---|
| walking gait pose | −15.55° | +44.44° | 85.11° | — |
| what STAND commanded | +90.00° | 0.00° | 180.00° | — |
| instantaneous error | **+105.6°** | −44.4° | +94.9° | **68.6 cm** |

`kp = 0.8` saturates above 1.25° of error, so that is full duty on every joint:
precisely the slam the whole Home → Stand → Go sequence exists to prevent.

**Fixed by making STAND mean the right thing in both states.** From rest it is
still the Cartesian ramp out of HOME_POSE. While walking it now calls the new
`settle_to_stand()`, a direct one-shot move of all four legs to `stand_pose` —
the same 2-entry buffer `handle_recovery` already sends the non-aborting legs,
and accepted there for the same reason. Measured worst case from *any* walking
gait pose (15 cm steering stride, body shift on) is **16.3° at a joint / 9.2 cm
at the foot**, against 105.6° / 68.6 cm before.

Side effect worth knowing: this is the first way to halt a robot that is on its
feet without dropping it. STOP cuts holding torque and lets it sag; STAND now
stops the walk and holds the stance powered. The dashboard says so.

Not a full fix for the missing zero-velocity state (see "No stop command
mid-turn" below) — there is still no "keep walking forward at 0 speed".

---

## RESOLVED — one InverseKinematics shared across threads returned wrong angles

`calculate()` stored its answer on the engine (`self.roll/pitch/knee`) and
returned `self`, so the caller read the angles off shared mutable state *after*
the call returned. `pi5_main` has a single `self.ik_engine`, used from:

- the main control loop — `build_gait()` → `GaitIK` → `calculate()`
- ROS executor threads — `stand_callback`/`go_callback` → `build_ramp()` →
  `cartesian_ramp()` → `calculate()`

Those genuinely overlap (the STAND-while-walking path above is exactly such a
case), and when they do, one thread reads the other thread's joint targets —
which then go straight to a motor. Measured with the GIL switch interval forced
low: **60% of solves corrupted** (24066 of 40000). At the default 5 ms switch
interval it is rare rather than impossible, which is the worst kind of bug.

**Fixed:** `calculate()` now returns an `IKSolution` — a small `__slots__`
object carrying its own roll/pitch/knee — and every intermediate in the solve is
a local. The engine holds only the segment lengths, which are read-only after
construction, so it is safe to share. Attribute names are unchanged, so all four
call sites needed no edit. Re-measured after the fix: **0 of 40000 corrupted.**

Related and also fixed: `request_stand()` and `engage_walking()` were writing
`self.standing` / `self.walking_enabled` without holding `serial_lock`, while
`publish_homing_status()` reads them under it.

---

## Swing clearance is 4.76 cm, not the nominal 5.0

`SWING_HEIGHT = 5.0` is the *continuous* peak of `h1·sin(πs)`, but the swing is
sampled at only 5 points — `s = 0, 0.2, 0.4, 0.6, 0.8` — which never lands on
the `s = 0.5` peak. The highest commanded lift is `5.0·sin(0.4π) = 4.755 cm`.

This matters because it appears in a safety argument: the PID tuning section
below reasons that 9.4° of peak tracking error is "~4 cm at the foot, against
5 cm of commanded swing clearance". The real figure is **4.76 cm**, so the
margin is 0.76 cm rather than 1.0 — about 25% thinner than stated. Still
positive, still needs the bench check that section already asks for.

Raising the swing sample count (a larger `num_steps`, or a finer swing fraction)
would both recover the nominal clearance and soften the liftoff/touchdown corner
that drives the peak joint rate — see `STEP_TICK_MS` below, which wants the same
thing for a different reason.

---

## Not a defect: stance y quantisation

Recorded because it looks like one. `GaitPath.generate_path` rounds each
coordinate to 2 dp, so consecutive stance steps differ by −0.66 or −0.67 cm
rather than a constant −0.667. The underlying formula is exactly linear
(verified: unrounded deltas are a single value); the variation is 0.005 cm of
rounding, 0.05 mm at the foot. The elliptical-stance scrub the design
deliberately rejects is 0.85 cm/tick — **170× larger**. Nothing to do here.

---

## Obstacle avoidance — built and simulated, never run on hardware

`vision_obstacle.py` plus the dashboard toggle. The planner logic is verified
(`python vision_obstacle.py` runs a self-test; a closed-loop sim against the real
`Navigator` showed obstacles struck by 0.95 m with avoidance off cleared by
0.25–0.50 m with it on, no oscillation). **None of the perception side has been
checked against a real camera on the real robot**, and several numbers are
educated guesses until it is.

### Tune these on the bench before trusting it outdoors

- **`ROI_TOP` / `ROI_BOTTOM` (0.45 / 0.95).** Which band of the frame counts as
  "the ground ahead". Depends entirely on where the camera is physically mounted
  and at what angle — a guess until checked against a real still. Too high and it
  reads the sky as clear; too low and it stares at the robot's own nose. Turn
  avoidance on and look at the overlay on the dashboard feed.
- **`OBSTACLE_MARGIN` (0.12).** How much nearer than its own row's ground a pixel
  must read before it counts. Measured insensitive between 0.05 and 0.25 on the
  synthetic scenes, so it is not a knife edge, but it has never met real terrain
  texture. Raise it if grass or gravel trips it, lower it if low obstacles slip
  through. (This replaced an absolute `NEAR_THRESH` — see below.)
- **`FLAT_GRADIENT_MIN` (0.10).** Only fires for a column with no near/far
  contrast at all, i.e. something filling the view. A camera angled further down
  sees less depth range in the band, which shrinks every column's gradient and
  makes false "blocked" more likely — check this once the mount is final.
  Raising it halts more readily, which is the safe direction.
- **`FOV_DEG` (60.0).** Assumed, not measured. Only scales bin index → steering
  angle, so an error here makes turns consistently too shallow or too sharp
  rather than breaking detection.
- **`CLEAR_HOLD_S` (20.0).** How long to drive straight after the obstacle leaves
  view before handing steering back to the navigator. This is the number that
  decides clearing vs. grazing — see the comment on it for the swept data. It is
  a time standing in for a distance because there is no odometry, so it is only
  correct at the assumed ~10 cm/s avoidance speed. **If `STEP_TICK_MS` or the
  base stride changes, this needs re-deriving.**

### RESOLVED — an absolute depth threshold read the ground as an obstacle

Found on a real capture: a person standing in the middle of an otherwise clear
path, with both sides plainly open, reported **fully blocked**. The depth model
was fine — the figure was cleanly segmented — the costmap was wrong.

For a forward-facing camera on flat ground, the distance to the ground at image
row `r` goes as `1/(r - horizon)`, so the inverse depth the model emits ramps
smoothly from far at the top of the frame to near at the bottom. The bottom of
the ROI is therefore *always* near: it is the ground half a metre in front of the
feet. `NEAR_THRESH = 0.55` flagged that ground everywhere. Reproduced on a
synthetic scene built from the flat-ground equation: **bare open ground scored
0.42 in every bin** against a 0.25 block threshold.

**Fixed** by making detection ground-relative: a pixel is an obstacle when it
reads `OBSTACLE_MARGIN` nearer than that row's own `GROUND_REF_PCT` percentile.
An upright object occupies rows that would otherwise show ground far away, so it
stands out sharply. The reference percentile sits below the median deliberately,
so a wide object cannot drag it up to its own depth and hide itself. A separate
per-bin flat-gradient test catches the one thing the relative test cannot see —
something filling a column top to bottom, leaving no contrast to find.

| scene | before | after |
|---|---|---|
| open ground | `#########` | `.........` |
| figure dead centre | `#########` | `....#....` |
| figure on the right | `#########` | `.......#.` |
| wall filling the view | `#########` | `#########` |

A useful property that fell out of it: because the reference comes from the row
itself, a **uniform slope shifts the whole row together and is not flagged**.
Only localised protrusions are, which is what you want on terrain.

These four scenes are now a regression test in `python vision_obstacle.py`, and
the tuning notebook imports the module rather than keeping its own copy of the
pipeline — the two had already diverged once.

### Known limits of the approach itself

- **Monocular depth is relative, not metric.** No true distances, and the scale
  shifts frame to frame. Fine for "something bulky is close", weak for judging
  gap widths.
- **Drop-offs and holes read as *farther* than the ground, never nearer, so the
  detector cannot flag them at all.** This is inherent to the method, not a
  tuning problem: the test asks "is anything closer than the ground should be",
  and a hole is the opposite. The FSR / `ABORTED` recovery path is the only
  backstop, and it only fires on contact.
- **Body width is handled by a fixed angle, but the correct angle depends on
  range.** What has to fit through a gap is ~72 cm (53 cm hip spacing plus the
  abductor sticking out ~9.65 cm each side — *not* the 53 cm `BODY_WIDTH_CM`).
  That subtends 71.7° at 0.5 m but only 20.5° at 2 m — 10.8 bins down to 3.1 —
  and the costmap has no depth axis to tell those apart, since the ROI band
  flattens roughly 0.5–2 m into one row of bins. `CORRIDOR_BINS=3` plus
  `INFLATE_BINS=1` enforces a flat 33.3°, which matches the true width only
  beyond **~1.2 m**; nearer than that it under-provisions on paper, and relies
  on a close obstacle filling enough bins to trip `BLOCKED` instead. Fixing this
  properly needs a range-resolved costmap (split the ROI into near/far rows and
  require a wider corridor in the near row), not a bigger constant — raising
  `CORRIDOR_BINS` to 5 demands 46.7° of a 60° view and leaves almost nothing
  passable.
- **Thin obstacles are unreliable.** Table legs and wires are close to the
  resolution limit at `INPUT_SIZE = 266` and may not survive the bin averaging.
- **No reverse.** Steering is a body yaw now (see the steering entry below), so
  the robot *can* spin in place — `ESCAPE` and a hard turn command both do — but
  it still cannot walk backward. A robot nose-first in a dead end can rotate to
  face out, which the old differential steering could not do, but if it is
  wedged it still needs a human.
- **`BLOCKED` halts by setting stride to 0**, which makes the feet lift and land
  in the same spot — it keeps standing and stays IMU-levelled. This is
  deliberately *not* the dashboard STOP, which cuts holding torque and would let
  a standing robot sag. Verified: `GaitPath` with `length=0` gives all feet
  `y = 0.0` with 4 airborne steps still in the cycle.
- **Fails open, not closed.** A stale costmap (camera died, worker stalled,
  older than `STALE_AFTER_S`) drops back to normal walking rather than halting.
  That is the right call for a slow robot with a human nearby, but it does mean
  a silently dead camera looks like "avoidance is on and the path is clear".
  Watch the dashboard state readout.
- **CPU contention is unmeasured.** Inference is capped at
  `cpu_count - 2` threads to leave room for the 100 Hz control loop and the four
  serial writers, but the effect on control-loop timing has not been measured on
  a loaded Pi 5.

### Validated against real ground-robot imagery

The tuning notebook's Test 1 now runs eight photographs taken from actual ground
robots — camera low, pointed straight ahead, ground plane filling the lower
frame — rather than scenic stills. Two results are worth carrying forward:

- **`INFLATE_BINS = 1` is load-bearing.** Dropping it to 0 makes an indoor
  corridor with a wall down each side report CLEAR. Confirmed on real imagery,
  not just simulation.
- **A trail that looks walkable reports BLOCKED, correctly.** Its clear gap
  measures 26.7°, which against the 72 cm body is 47 cm at 1 m, 71 cm at 1.5 m,
  95 cm at 2 m — genuinely too tight near, fine further out. A good illustration
  of the range-dependence limitation above: the costmap has no depth axis, so it
  cannot express "tight now, fine in a metre" and halts instead.
- **A low cardboard box on paving, several metres out, is missed.** Too few
  pixels clear `OBSTACLE_MARGIN` for its bin to reach `BLOCK_FRAC`. It would be
  seen on approach. Low obstacles at distance are the weak spot, with the
  `ABORTED` foot-contact path as the only backstop.

### First hardware session should be, in order

1. Robot on a stand, off the ground. Toggle avoidance on, watch the overlay, and
   tune `ROI_*` and `NEAR_THRESH` against real obstacles at real distances.
2. Check the reported inference time on the dashboard; confirm the control loop
   is not visibly stuttering.
3. Only then, on the ground, in manual mode, walk it at a single obstacle.
4. GPS/autonomous mode last.

---

## PLANNED — migrate ground-contact sensing from FSR to current sensing

Decided direction, not yet implemented. Ground contact (used only for the abort
check — a foot touching down early, mid-swing, triggers `handle_recovery`) currently
comes from four digital FSR pins in `Pico/fsr.py`, one per leg, read as a plain
GPIO high/low through a physical pull-down resistor: `fsrs = [FSR(16), FSR(17),
FSR(18), FSR(19))]`, and `any_touchdown = any(f.state for f in fsrs)` in
`pico_main.py`. The plan is to replace this with current sensing on the joint
motors instead — detecting a stall/current spike (the leg meeting unexpected
resistance) rather than a dedicated foot-mounted pressure sensor.

**Not designed yet — flagging what the migration actually has to answer, not
guessing at it:**
- *Where the current gets measured.* **Per-joint, off the BTS7960's own `IS` pins**
  — see the callout at the top of this file. The sense element is already in the
  driver chip (a ~1/8500 current mirror), so this needs a sense resistor and an ADC
  pin per joint, not a new shunt. It is also not 12 readings gathered centrally:
  each Pico only reads its *own* three joints, and `GP26`/`GP27`/`GP28` (ADC0/1/2)
  are free on every board for exactly that. The existing `INA219` in
  `power_monitor.py` reads total *pack* current only — one number for the whole
  robot, not per-leg, so it cannot answer "which foot touched down" on its own.
- *Stall vs. touchdown are not the same event.* A current spike means the leg met
  resistance — that's also true for hitting an obstacle mid-swing, binding at a
  joint limit, or simple stiction, not only "foot reached the ground." The FSR is
  specific to ground contact; current sensing is a broader "something stopped this
  joint" signal and will need its own logic to distinguish the cases (or the
  abort logic needs to become "the leg stalled," a real semantic change, not just a
  sensor swap).
- *Threshold tuning is different, not simpler.* FSR threshold is a fixed digital
  high/low against a known resistor. A current threshold has to sit above normal
  swing-phase motor current (which itself varies with `kp`/duty cycle, bench-tuning
  which is already an open item above) and below a stall — those two need to be far
  enough apart under real load to have a safe midpoint.

**Keep this in mind for other work, not just this entry:** any future change
touching `fsr.py`, the abort/`ABORTED` protocol, or `handle_recovery` should treat
FSR as the *current, temporary* mechanism, not a permanent architecture decision —
don't build more FSR-specific tooling or tuning on top of it without checking
whether this migration has since landed.

---

## PLANNED — ship one generic UF2 with the Pico files preloaded

Idea, not built. Right now, setting up a Pico is two steps: flash a stock
MicroPython `.uf2` (drag-and-drop in BOOTSEL mode), then copy `pico_main.py`
(as `main.py`), `motor_control.py`, and `fsr.py` onto it separately (Thonny,
`mpremote`, or similar). The second step is also where `LEG_ID`, `FSR_PIN`, and
the per-joint `reverse` flags get set for that specific leg before copying.

The idea is to collapse the first step into the second: build one combined
`.uf2` that already contains both the MicroPython interpreter and the default
copies of these three files, so flashing it is a single drag-and-drop and the
Pico boots with the files already in place — as ordinary files on its real
filesystem, not compiled in, so they're still just as editable in Thonny
afterward. Each of the 4 boards would still need someone to open `main.py` and
change `LEG_ID`/`reverse`/`FSR_PIN` for that leg, same as today; this only
removes the separate copy step, not the per-board configuration.

**This is not the same as freezing the code into firmware**, which was also
considered and rejected earlier in this project for the same reason: frozen
modules are compiled into read-only program flash, not visible or editable as
files, so anyone tuning `LEG_ID` or a `reverse` flag would need a full firmware
rebuild instead of an edit in Thonny. A preloaded filesystem avoids that —
the files are real, writable files from the moment the board boots.

**How it would actually work:** a `.uf2` file is a sequence of independent,
self-addressed 512-byte blocks — each block carries its own target flash
address, so a valid `.uf2` can be assembled by writing to different regions in
one file. Concretely:

1. Take the stock MicroPython `.uf2` for the RP2040 (interpreter only, empty
   filesystem).
2. Separately build a small littlefs filesystem image — MicroPython's default
   internal filesystem format on RP2040 — containing the three files above with
   their default values already in place.
3. Convert that filesystem image into `.uf2` blocks targeting the flash address
   where that specific MicroPython build expects its filesystem to live.
4. Concatenate the firmware `.uf2` and the filesystem `.uf2` into one file.
   Flashing the combined file performs both writes in the one BOOTSEL
   drag-and-drop.

**The real cost, and why this is parked rather than built:** the filesystem's
flash offset in step 3 is specific to the exact MicroPython firmware build the
combined image starts from. Pull a newer MicroPython release later and that
offset can shift, silently landing the preloaded files in the wrong place —
so a combined image has to be treated as a build artifact pinned to one named
MicroPython version, not a file to hand out and forget. Given all 4 boards
still need per-board hand-editing regardless, this buys back exactly one
drag-and-drop step per board, at the cost of maintaining and re-verifying that
pin every time the MicroPython version changes. Worth doing if reflashing
boards from scratch becomes routine (a build run, new hardware); not worth it
for the occasional reflash this project does today.

---

## Homing — a manual step you have to do, before every power-on

Every Pico's encoder starts counting from wherever the leg physically is when it
boots — the firmware has no way to know the real angle on its own. It currently
assumes `initial_angle=0`, but the IK's neutral standing pose is
**roll −15.55°, pitch 44.4°, knee 85.1°**, not zero. So the first gait frame used to
command ~45° and ~95° of travel from a wrong assumed position, at effectively full
PWM. **Resolved below — the whole flow (Home → Stand → Go → Stop) is built and
verified; one open question about mechanical confirmation remains at the end.**

**Manual, mechanical, not automated: before powering on, position each leg by hand**
into this reference pose, one leg at a time, and treat that as the zero point:

- **Hip roll = 90°** — abductor perpendicular to the body, pointing up.
- **Knee = 180°** — locked straight, thigh and shin colinear.
- **Hip pitch = 0°** — the leg (thigh+shin, straight) perpendicular to the body's
  lengthwise axis, no fore/aft lean.

This isn't a guess — it's derived from that description using the actual IK/FK code:
with the knee locked straight the thigh-shin triangle degenerates, which forces the
knee-side interior angle to exactly 0° regardless of segment length, which in turn
forces pitch = 0° to be the *exact* angle with zero fore/aft foot offset (verified:
`calculate_fk(90, 0, 180)` gives y = 0.0000 cm, and round-trips back through
`calculate()` to the same three angles). See `HOME_POSE` in `ik_and_gait.py`.

All four legs get commanded the identical standardized angles here — it's each
joint's `reverse` flag on the Pico that makes the same command swing each leg out to
its own correct physical side.

### RESOLVED — Home button, one leg at a time
How does the firmware know a leg has been placed and is ready to be zeroed? It
doesn't, on its own — the human says so, one leg at a time, from the web dashboard.
Each Pico recognizes a 2-byte `HOME_MARKER` (`0xAB 0xAB`, distinct from the gait
protocol's `0xAA 0xAA` start marker) that means "wherever I physically am right now
IS HOME_POSE" — it calls `zero_at()` on all three joints (new on `JointController`,
same formula as the `initial_angle` setup in `__init__`, just callable after boot),
then acks `HOMED,<id>\n`. **Nothing moves when this runs** — it only redefines what
the encoder count means.

The dashboard has a `Home FL` / `Home FR` / `Home RR` / `Home RL` button, one per
leg, exactly as planned ("each leg gets homed independently 1 by 1"). `pi5_main.py`
tracks `self.homed[leg_id]`, sourced only from the Pico's ack (not just "we sent the
command"), and `request_stand()` / `engage_walking()` both hard-refuse — server-side,
not just a greyed-out button — unless every leg reports homed.

### RESOLVED — boot no longer moves the legs
It used to ramp straight into the walking gait as soon as it powered up, which —
combined with the fact that nothing verified homing had actually happened — meant an
unhomed robot would still slam its legs to wherever the gait's first frame put them.
Boot now only runs leg identification and prints a reminder; every Pico just holds
its power-on position (target 0,0,0) under light PID, which is what produces the
small holding jiggle rather than a real move. Motion only starts once the operator,
in order: homes all four legs, presses **Stand**, then **Go** (both below).

### RESOLVED — smooth ramps instead of one big jump: Stand and Go
Even with homing done correctly, going straight from HOME_POSE into the walking
gait's first step is itself a big move (**105° of roll, 44° of pitch, 95° of knee**
— see the table below). `ik_and_gait.cartesian_ramp()` interpolates a move like that
in a straight line in foot-position space over 40 steps; `pi5_main.build_ramp()`
wraps it for any fixed start pose → per-leg target. Verified: a ramp starts exactly
at its start pose, ends at its target, and the intermediate foot path is a straight
line to within 0.02 cm (rounding).

That one big jump is now split into two smaller, explicitly user-triggered moves
instead of a single automatic one at boot:

- **Stand** (`request_stand()`) ramps every leg from HOME_POSE into a static,
  feet-under-hips pose (`self.stand_pose`) — refuses unless every leg is homed.
- **Go** (`engage_walking()`) ramps from `self.stand_pose` into the walking gait's
  first frame, then starts the continuous cyclic walk — refuses unless the robot is
  already standing.

| joint | HOME_POSE | gait neutral stance | travel |
|---|---|---|---|
| roll  | 90.0°  | −15.55° | −105.5° |
| pitch | 0.0° | 44.44°  | +44.4°  |
| knee  | 180.0° | 85.11°  | −94.9°  |

(Table is the original single HOME_POSE → gait-neutral jump that motivated building
a ramp at all — the numbers above show why slamming straight there was the problem
in the first place. Stand and Go now cover that distance in two separately-gated
hops rather than one.)

Sending a one-shot ramp to all four legs at once (rather than one leg's recovery
path) needed a small worker change: the normal cyclic-gait path always phase-offsets
each leg's buffer index and always ends with the *cycle* marker. A one-shot,
multi-leg send needs neither — the four ramps are independent point-to-point paths,
not a shared cycle sampled at different phases, so applying the phase rotation would
have each leg read a different, wrong ramp entry (verified this directly: with the
real offsets applied, a nonzero-offset leg samples the wrong entry; with offsets
zeroed, every leg samples its own ramp correctly). `send_entire_gait()` takes a
`cycle` flag, and the worker picks offsets `[0,0,0,0]` and the one-shot marker when
`cycle=False`.

### RESOLVED — Stop
Every Pico recognizes a third 2-byte command, `RELAX_MARKER` (`0xAC 0xAC`), that cuts
PWM to zero on all three joints without touching `gait_buffer`, `current_targets`, or
the encoder ISR. Pressing **STOP** on the dashboard sends this to every identified
leg, and also clears `walking_enabled`/`standing` on the Pi so the cyclic gait stops
being re-sent. Power resumes automatically — no separate "resume" command — the
moment either a `HOME` command or a complete gait/ramp frame arrives, which is what
pressing **Home** or **Stand** again naturally does.

**Read this before using it:** Stop does not lower the robot into any kind of
resting pose first. If the robot is standing or walking under its own weight when
you press it, cutting power will let the legs sag or the robot collapse the instant
torque drops — there is no sit-down sequence. It's built for "the robot is already
off the ground or otherwise supported and I want to relax the motors without losing
homing," not as a safe way to halt a walking robot mid-stride.

### Bug caught while building Stand/Go, not previously exercised
`cartesian_ramp()` unpacked its target with `calculate_fk(*target_angles)`. A
gait-frame entry is `[roll, pitch, knee, is_swing]` — 4 elements — so this raised
`TypeError` the moment it ran against a real gait frame instead of the 3-element
tuples the one existing test used. It would have crashed the first `engage_walking()`
call (and, before that, the original boot-time ramp) the first time it actually ran,
on hardware, with `rclpy` installed. Fixed by slicing to `[:3]` before unpacking.

### Still open, and worth deciding before any of this is trusted
Homing has no mechanical confirmation at all — if a leg is 10° off from the real
pose when you press its button, the firmware has no way to notice. It's a straight
trust-the-human step, just now a button press instead of "power on and hope." A hard
stop or limit switch would close this gap; not built here since it needs a decision
about the mechanism.

---

## Before you walk it

### Set LEG_ID on each Pico
`pico_main.py` has a `LEG_ID` constant at the top. Each of the four boards needs a
**different** value matching the corner it is bolted to:

| `LEG_ID` | Corner |
|---|---|
| `0` | Front Left |
| `1` | Front Right |
| `2` | Rear Right |
| `3` | Rear Left |

Each board announces `LEG,<id>` over UART every 500ms until it receives its first
gait frame, and the Pi builds the port→corner map from that — so UART wiring order
no longer matters. But two boards sharing an ID, or one set to the wrong corner,
produces a wrong gait phase and the robot falls. **The Pi logs the map it detects at
startup; check it before any powered walking.**

Confirmed on re-review that a *duplicate* ID fails safe rather than dangerously:
the second board to claim an ID is logged as an error and never enters
`port_by_leg`, so `request_home_leg` refuses it, `all(self.homed.values())` never
becomes true, and STAND is refused. You get a robot that will not stand, not one
that walks on three legs. A *wrong but unique* ID does not fail safe — all four
home, and the gait phases go to the wrong corners. Check the logged map.

### Set the left/right `reverse` flags — now matters for turning, verify it
The joint setup in `pico_main.py` takes a `reverse` argument per joint, currently
`False` everywhere. Left and right legs are mirror-image copies — the abductor
segment sticks outboard on both sides — and a reflection reverses handedness, so
one side needs its motor polarity flipped. Manual per-board setting, like `LEG_ID`.

**"The commanded angles are identical either way" is only true while walking
straight.** Verified: `build_gait` commands FL ≡ FR and RL ≡ RR joint-for-joint
at `yaw_deg == 0`, so `reverse` does the entire left/right mirror. But a **turn**
commands left ≠ right — a body spin rotates every foot the *same* angular
direction about the centre, which is a rotation between the two sides, not a
reflection, so `reverse` alone cannot produce it. `body_twist_xy_path` converts
the arc into each leg's own local frame with `LEG_SIGN_X`, and `reverse` then
maps that to physical motion. The turn *kinematics* are verified in
`quadruped_sim --report` (body spins the correct direction, margin/rate hold),
but the sim does not model `reverse`, so **whether the `reverse` flags compose
correctly with a turn is a bench check** — do it on a stand, off the ground,
before any powered turning.

### Verify the IMU roll/pitch signs — do this one first
On a stand, legs off the ground, watch the `[IMU Reflex] Levelling. Roll ...
pitch ...` line: tipping the chassis **right side down** must print a **positive
roll**, and **nose up** must print a **positive pitch**. If either is backwards,
flip that term's sign in `ik_and_gait.attitude_height_offsets()`.

Get this wrong and the levelling is positive feedback — it grows the tilt instead
of cancelling it, up to 8.6° of self-inflicted lean against a 2.4 cm stability
margin. Full write-up and the numbers: *Will make the robot fall over → OPEN — the
IMU roll/pitch signs are unverified*.

### Front/rear mirroring is handled in software — verified
The IK solves a **knee-forward** leg: at neutral stance the knee node sits at
local y = +18.8 cm. That matches the **rear** pair. The **front** pair is bolted
on turned round so its knees point back (toward the rear knees, as on a real
dog), so the front legs' stride is mirrored in software: `LEG_SIGN_Y = -1` for
the front pair, applied inside `body_twist_xy_path` (this replaced the old
`mirror_y=(leg_id in FRONT_LEGS)` flag; the two are equivalent and
`body_twist_xy_path` at `yaw == 0` reproduces the old gait term for term).

Verified numerically: during stance the front feet travel one way in their
*local* frame and the rear feet the opposite way, but `LEG_SIGN_Y` makes all
four move **backward in the body frame** together — which is what drives the
body forward. Without the flip the front legs would push against the rear.

It is a spatial mirror, **not** a time reversal. Reversing the cycle would also
shift each flipped leg half a cycle and scramble the FL → RR → FR → RL crawl
order.

**One thing `LEG_SIGN_Y` does NOT do, and must not be confused with:** it mirrors
the *stride direction*, not the *knee bend direction*. Whether a given knee angle
bends the joint fore or aft is a property of the assembly and the `reverse` flag
on that joint's `JointController`, not of the gait. So "the front knees face the
rear knees" is handled in two separate places — stride by `LEG_SIGN_Y` (verified
above, in software), bend direction by the per-joint `reverse` flags (still all
`False`, still a bench check — see the entry above this one). Getting
`LEG_SIGN_Y` right does not tell you the `reverse` flags are right.

A stale docstring on `GaitPath.update_params` used to say `mirror_y` applied to
"the rear pair, whose knees point forward", contradicting `FRONT_LEGS` three
screens above it. The code was always right (front pair mirrored); the comment
has been corrected.

### Body geometry (set — recorded here because it lives nowhere else)
`quadruped_sim.py` uses `BODY_LENGTH = 67.5`, `BODY_WIDTH = 53.0` cm. Both are
**hip-pivot spacings**, which is what the support polygon is built from — the shell
is 950mm end to end, but the hip pitch axes are only 675mm apart. Using the outer
length here would flatter the stability margin.

Same file has `LEG_FLIP_X` / `LEG_FLIP_Y`, modelling left-right mirroring and the
front pair's reversed mounting. `mirror_y` is derived from `LEG_FLIP_Y`, so the
mount model and the gait cannot silently disagree — but if your mechanical layout
differs from what those tables say, fix them or the sim will lie to you.

---

## Debug tool: per-leg deactivation

The dashboard has a `Deactivate <leg>` / `Reactivate <leg>` toggle per leg, for
bench testing. Deactivating a leg does **not** change the gait loop in any way —
`pi5_main.py` still computes that leg's target every tick exactly as if nothing
were deactivated — it only skips the wire write (open marker, per-step payload, and
close marker, all three) for that leg's Pico. That Pico is left completely alone:
no empty frame, no reset, it just keeps holding whatever it was last actually told.
The other three keep walking normally.

Does not touch `self.homed` — deactivating and reactivating a leg never requires
re-homing it. Intended for isolating one leg's Pico on the bench (or watching the
other three walk without one leg's motion muddying the picture), not for anything
load-bearing: a deactivated leg gets no updated commands at all, so if it was mid-air
when deactivated, it stays exactly there.

---

## Will make the robot fall over

### OPEN — the IMU roll/pitch signs are unverified, and a wrong one is positive feedback

**The only open item in this section, and the most dangerous unverified thing in
the codebase.** Nothing in the code or the simulator can detect it; it needs two
minutes on a stand.

`attitude_height_offsets()` levels the body by making the legs on the low side
longer and the legs on the high side shorter. To know which side is low it trusts
a convention: **positive roll = right side down, positive pitch = nose up.** The
maths is correct *for that convention* — `dz = gain * (hx*tan(r) - hy*tan(p))`
extends the right legs when `r > 0` (`hx` is +26.5 cm there) and shortens the
front legs when `p > 0` (`hy` is +33.75 cm), both restoring.

But roll and pitch come out of `IMU._quat_to_pitch_roll()` in the **BNO085's own
body frame**, and which physical direction that frame's axes point depends
entirely on how the breakout is bolted into the chassis. Rotate the board 180°
about its vertical axis and both signs flip. Mount it on its side and they swap.
The quaternion maths is standard and correct — the question is not "is the
conversion right", it is "does the board's +X actually point forward".

If either axis is inverted the correction runs the wrong way, which is **positive
feedback**: a small tilt produces a correction that increases the tilt, which
produces a bigger correction, until it saturates at `ATTITUDE_LIMIT_CM = 4.0`.

| | |
|---|---|
| Limit | 4.0 cm of differential leg height |
| Track width | 53.0 cm (`BODY_WIDTH_CM`) |
| Induced roll at the limit | `atan(8/53)` ≈ **8.6°** |
| Worst-case stance margin | +2.38 cm (`quadruped_sim --report`) |

8.6° of self-inflicted lean, added to whatever tilt started it, against a support
triangle with 2.4 cm of margin. The robot puts itself over, and it does it faster
the harder it tries to correct.

Why it has not bitten yet: `ATTITUDE_GAIN = 0.6` and the 12-sample IMU average
make the runaway take a second or two rather than being instant, and the robot has
never walked unsupported. It is also completely invisible in simulation —
`quadruped_sim` feeds `attitude_height_offsets` a *commanded* tilt, so the sign
convention is true by construction there and the sim will report a clean margin no
matter which way the real board is mounted.

**Bench check — on a stand, legs off the ground, before the robot ever carries its
own weight while walking:**

1. Bring the Pi up and watch the `[IMU Reflex] Levelling. Roll ... pitch ...` line.
2. Tip the chassis **right side down**. `Roll` must print **positive**.
3. Tip it **nose up**. `pitch` must print **positive**.
4. If either is backwards, flip that term's sign inside
   `ik_and_gait.attitude_height_offsets()` — the docstring says to fix it there
   and not anywhere downstream, so that `pi5_main` and `quadruped_sim` keep
   agreeing. Re-run `quadruped_sim.py --report` afterwards.

The same "we assume it, we have never measured it" gap applies to the compass axis
signs (see *Compass* below) and to the per-joint `reverse` flags during a turn (see
*Before you walk it*). This one is the worst of the three because its failure mode
is divergent rather than merely wrong.

### RESOLVED — body shift, phased with the lift sequence
The sim reported 100% "statically stable" but that was a binary in/out test hiding
the real number: the **margin** — distance from the body centre to the nearest edge
of the support triangle — had a worst case of **+0.42 cm** at 67.5 × 53 cm. The cause
is geometric: with feet directly under the hips, lifting one leg leaves a triangle
whose hypotenuse runs corner-to-corner *through* the body centre, on the edge by
construction. 4 mm gets consumed instantly by payload offset, the swinging leg's own
mass, or any ground unevenness.

`ik_and_gait.py` now has `body_shift_profile()`: it leans the body 2 cm toward the
diagonally-opposite hip from whichever leg is about to lift, one tick ahead of the
lift (during the four-feet-down beat), then leans back. `apply_body_shift()` folds
that into each leg's foot path in its own local frame. `pi5_main.build_gait()` calls
both; `quadruped_sim.py` calls the identical functions, so the two cannot disagree.

The first attempt used a box filter to smooth the profile and only reached +0.81 cm
— worse than expected. The filter was straddling the sign flip at each lift boundary,
which is also the instant the margin is thinnest, diluting the lean exactly when it
mattered. **No smoothing (`smooth_width=1`) is now the default**, verified against the
alternative — see the comment on `body_shift_profile` for the measured numbers.

Result: **worst-case margin is now +2.38 cm**, clearing the 2 cm bar, at a joint-rate
cost of 235 → 266 deg/s (65% → 74% of the motor's free speed — still 26% headroom).
`quadruped_sim.py --report` now shows `VERDICT: gait is viable`.

### RESOLVED — `height2` (stance push) set to 0
Three feet are planted at different points in the stance phase, so a nonzero
`height2` commanded them to depths spanning 2.17 cm — on flat rigid ground they
cannot all be there, and it becomes body bob or lost contact. `STANCE_PUSH` is now
`0.0` in `pi5_main.py`, `quadruped_sim.py`, and `single_leg_test.py`. Downward reach
for uneven terrain would need closed-loop FSR contact to do properly, not a fixed
per-step push — left for later, deliberately not brought back as a blind default.

### RESOLVED — `STEP_TICK_MS` raised 20 → 40 ms
Kept here because the tradeoff is worth understanding before anyone lowers it again.
40 ms gives a peak of 235 deg/s (65% of free speed) at 16.7 cm/s. The simulator now
checks this every run and fails if the commanded rate exceeds the motor.

Peak commanded joint rate, per phase, at the old 20 ms tick:

| phase | roll | pitch | knee |
|---|---|---|---|
| stance | 11 dps | 91 dps | 69 dps |
| **liftoff** | 71 dps | 253 dps | **469 dps** |
| swing | 51 dps | 345 dps | 299 dps |
| **touchdown** | 71 dps | 163 dps | **469 dps** |

The goBILDA 5302 at 99.5:1 / 60 RPM gives **360 deg/s at the output shaft, free
running**. The gait asks for **1.30x that** at liftoff and touchdown, and under the
load of a real quadruped nothing like 60 RPM is available. The PID will simply
saturate and the leg will lag its target — the foot lands late and in the wrong place.

The peaks are at the phase boundaries, not mid-swing: the foot reverses direction
there, and with only 4 swing samples that corner is sharp.

| `STEP_TICK_MS` | cycle | speed | peak rate | |
|---|---|---|---|---|
| 20 (current) | 0.40 s | 33.3 cm/s | 469 dps | too fast |
| 25 | 0.50 s | 26.7 cm/s | 375 dps | too fast |
| 30 | 0.60 s | 22.2 cm/s | 313 dps | 87% of free speed — still tight |
| **40** | 0.80 s | 16.7 cm/s | 235 dps | 65% — realistic under load |
| 50 | 1.00 s | 13.3 cm/s | 188 dps | conservative |

Not changed, because the right value depends on what the motors actually deliver
under load, which is a bench measurement rather than something derivable. **Start at
40 ms** and work down while watching whether the legs track their targets.

Softening the corner would also help — more swing samples, or easing the velocity
into liftoff/touchdown rather than starting the arc at full horizontal speed.

Note the same argument in Y is already handled — stance `y` is deliberately linear in
time so all planted feet travel at identical speed. An elliptical stance would make
them differ by up to 0.85 cm/tick (127% of a step) and scrub against the ground.

---

## Will misbehave

### RESOLVED — `current_state` conflated operating mode with transient activity

`RobotState` was one field used for two unrelated things: MANUAL/AUTONOMOUS
(what the operator asked for) and RECOVERY (what the robot is doing right now).
Three bugs followed, the middle one able to drop the robot:

1. After any recovery the worker hard-set `current_state = MANUAL`, so a stumble
   silently dropped the robot out of GPS nav while the dashboard still read
   NAV: ON.
2. `nav_mode_callback` overwrote `current_state` unconditionally from a ROS
   executor thread. A NAV toggle landing between `handle_recovery()` staging a
   recovery and `_gait_serial_worker` reading it flipped the worker's
   `== RECOVERY` test false — **the recovery was never transmitted, and the
   aborted leg stayed frozen at zero PWM with `has_aborted` latched while the
   other three kept walking.** That is a fall.
3. The worker's state check raced that same callback.

**Fixed** by splitting into two fields with one writer each:
`current_mode` (`RobotMode.MANUAL` / `AUTONOMOUS`) written only by
`nav_mode_callback`, and `current_activity` (`RobotActivity.NORMAL` /
`RECOVERY`) written only by the recovery path. The worker gates on
`current_activity`, which the nav toggle cannot touch, so (2) is structurally
impossible now; clearing a recovery no longer resets the mode, so (1) is gone;
and there is no longer a single field two threads fight over, so (3) is gone.
`RobotState` remains as a back-compat alias of `RobotMode` — `.RECOVERY` was
deliberately removed from it so a stale reference raises instead of silently
comparing a mode against an activity. Verified against the source: no
`current_state` in executable code, nav callback touches only `current_mode`,
recovery touches only `current_activity`.

### RESOLVED — one leg recovers while the other three keep walking: policy is "go to neutral"
`handle_recovery` used to send the recovery path only to `trigger_serial`, leaving
the other three legs cycling their existing walking buffer — trying to keep walking
on three legs while the fourth recovers. Policy decided: **go to neutral**, not
freeze in place. The other three are now sent, in the same recovery pass, a direct
one-shot move to `self.stand_pose` (the same static point the aborting leg's own
`get_recovery_gait` already targets) — so all four legs converge on the same
feet-under-hips pose. `standing`/`walking_enabled` are cleared when recovery starts
and `standing` is set once it completes, so **Go** is required to resume walking
rather than the robot silently continuing on whatever it was doing.

**Caveat, not fully solved:** the other three legs have no live position feedback —
the Pi only learns a leg's actual angle when *that* leg is the one that aborts and
reports it. So unlike the Home→Stand→Go ramps, this can't be a smooth Cartesian
interpolation from a known start; it's a direct PID move to `stand_pose`, bounded by
the same PWM limits as any ordinary gait step. Walking-gait poses stay close to
`stand_pose` by construction (that's the whole point of the stand height), so the
jump should be small, but it hasn't been measured on hardware.

### RESOLVED — steering is now a body twist (yaw), not differential stride

Was: `chosen_direction` mapped to a left/right stride-length difference, which
turned the robot like a skid-steer — every foot moving straight fore/aft, the
two sides covering different ground, the feet scrubbing sideways as the body
yawed. The hip-roll joint did almost nothing during a turn. `GaitPath`'s
`direction_angle` — nominally the omnidirectional mechanism — was hardcoded to
`0` everywhere and, tested, only strafed the body (translated it diagonally)
without ever yawing it.

Now: `ik_and_gait.body_twist_xy_path()` takes a forward stride **and** a yaw per
cycle. Each planted foot arcs about the body centre — its neutral (hip) position
rotated `± yaw/2` across the stroke — so the four feet phased together drive the
body through a real rotation, with the hip-roll joint carrying the lateral part
of each arc (this is how CHAMP / MIT-Cheetah-lineage controllers turn).
`pi5_main`'s loop maps `chosen_direction` (+ = turn right) to a yaw rate plus a
forward stride that tapers to zero by `YAW_FULL_SPIN_DEG` (90°), so a hard
LEFT/RIGHT spins in place and a moderate heading error arcs while still
advancing.

Verified in `quadruped_sim.py --report` across the full command range:
`yaw_deg == 0` reproduces the old straight gait **term for term** (margin
+2.38 cm, 266 deg/s, 55.8 cm/4 cyc — unchanged); every turn keeps one leg
airborne, the FL→RR→FR→RL crawl order, joint rate ≤ 283 deg/s (79%), and all
foot targets reachable. Full spin is ~13 deg/cycle → ~16 deg/s → a 90° turn in
~5.5 s.

**Still open / notes:**
- *There is still no zero-velocity "keep standing, hold heading" travel state.*
  `chosen_direction = 0` means walk forward. STOP de-powers; a large obstacle,
  or a completed mission, makes the loop march in place (stride 0) — feet lift,
  body holds, no ground covered. That covers mission end (now RESOLVED, below),
  but it is not a true "stand still and hold this heading" state.
- *A "spin in place" drifts.* The phased crawl means only 3 feet are planted at
  any instant, so each single-leg lift during a spin leaves a few mm of
  un-cancelled translation — measured 3–8 cm of drift over a 53° spin, and
  slightly asymmetric left vs right (the front-leg mirror). Nav recomputes the
  bearing from GPS every cycle so it self-corrects; a true zero-drift spin would
  need the arc centred on the support-triangle centroid, not the body centre.
- *`direction_angle` in `GaitPath` is now dead* for production (still used by
  `gait_testing3.py`). Left in place; `build_gait` no longer calls `GaitPath`
  for the gait itself, only `swing_steps()` uses it (for the lift schedule).
- The `TURN_BODY_SHIFT_CM` ramp (2 → 4 cm of tripod lean as the turn tightens)
  is what keeps the margin up during a turn — see its comment. Straight walking
  is untouched.
- `chosen_direction` still means "travel direction" in MANUAL and "heading
  error" in AUTONOMOUS — one variable, two meanings. Harmless with the yaw
  mapping (both want "yaw toward this"), but the `current_state` conflation
  above is the related cleanup.

### RESOLVED — mission end now holds position; route is editable from the dashboard

`Navigator.calculate_nav` returns `None` once the waypoints are exhausted. The
control loop used to let `chosen_direction` fall through to the last manual
value, so the robot walked off forever. It now sets `chosen_direction = 0` and
`stride_scale = 0.0` on that `None` — the march-in-place command from the
avoidance work — so the robot picks its feet up on the spot, stays standing and
IMU-levelled, and waits for STAND or STOP. The avoidance planner's stride is
folded in with `min()` now, not assignment, so a CLEAR decision (1.0) can no
longer undo that hold.

This also depended on there being a route at all. There wasn't a way to enter
one — `MISSION_WAYPOINTS` was two hardcoded pairs in `main()`. Now:

- `Navigator` takes an optional list, defaults to empty, and is fully
  lock-guarded (`set_waypoints` / `get_waypoints` / `progress` /
  `mission_complete`) because the control loop reads it at ~100 Hz while a ROS
  executor thread may be rewriting it. `set_waypoints` validates lat/lon range
  and always restarts the route at index 0.
- New topic `/apex/navigation/waypoints` (`Float32MultiArray`, flat
  `[lat, lon, ...]`, empty = "no route"). `waypoints_callback` on the
  controller hands it to `Navigator`.
- New topic `/apex/navigation/nav_cmd` (`Int32`: 1 START, 2 PAUSE, 3 STOP).
  START sets `AUTONOMOUS` + `reset_progress()` + clears pause; PAUSE sets
  `nav_paused` (the loop then marches in place without advancing the route);
  STOP returns to `MANUAL` + rewinds. `nav_paused` is a separate field, touched
  only by `nav_cmd_callback` and the loop.
- `stream_server` gains `/waypoints`, `/set_waypoints` and `/nav_control`
  (POST `action=start|pause|stop`). The status array grew four appended fields
  — `wp_index`, `wp_total` (`len >= 17`) then `nav_mode`, `nav_paused`
  (`len >= 19`) — so an older dashboard still parses.
- The dashboard's old standalone **Route** and **Obstacle Avoidance** cards are
  now one **Navigation** card with two collapsible sections (both start closed):
  *GPS Waypoints & Routing* (the NAV MODE master toggle, the point editor, and a
  **Start / Pause / Stop** transport row that greys out per state) and
  *Obstacle Avoidance* (the avoidance toggle + state readout, unchanged). The
  route status line reads e.g. "PAUSED — driving to waypoint 2 of 3".

NAV MODE and Start are now refused outright until a route is loaded, rather than
flipping AUTONOMOUS on to march in place. Three layers: the dashboard greys the
toggle out (`wp_total === 0`), `stream_server.toggle_nav` / `nav_control` return
409 without publishing, and `nav_mode_callback` / `nav_cmd_callback` in the
controller bail on `_route_loaded()` — so a message that bypasses the UI (replayed
topic, direct publish) still can't put the robot in nav mode with nowhere to go.
Verified end to end without hardware (`Navigator` editing, arrival advance,
concurrent-access smoke, `stream_server` route + `nav_control` publish, the
no-route refusals at every layer, 19-field status parse, and the preview server
driving a route through start → pause → stop).

Note the drift caveat from the steering entry above still applies to any turn,
and there is still no separate "hold heading while stationary" state — but
mission end is no longer one of the things that needs it.

### RESOLVED — blocking sensor reads moved off the control loop
The `while rclpy.ok()` loop in `pi5_main.main()` used to call `imu.update()`,
`compass.get_heading()` and (once a second) the INA219 reads **inline, every
iteration**. Those are synchronous I2C transactions — a few ms on a healthy bus,
but on a NAKing or wedged bus the kernel blocks for its I2C timeout, and while it
blocked so did steering resends, the IMU reflex and the avoidance stride command.

`sensor_hub.SensorHub` now runs one poller thread per sensor (IMU 50 Hz, GPS +
compass 10 Hz, INA219 1 Hz); each thread owns its hardware object exclusively and
publishes into a lock-protected snapshot. The loop reads `imu_snapshot()` /
`nav_snapshot()` / `power_snapshot()` — dict copies, never hardware — each with a
staleness cutoff, so a dead or hung sensor degrades to the safe default (flat
attitude, hold last heading, skip the battery check) instead of stalling the
gait. Two failure signals: snapshot freshness (poll ran, reading was bad/old) and
`thread_alive()` (poller blocked inside a hardware call right now); the loop logs
which poller is stalled every ~5 s via `SensorHub.health()`.

`GPSReader.update()` was already non-blocking (drains the UART buffer only) — it
rides the nav poller just to keep all sensor I/O in one place.
`CompassReader.get_heading()` now returns `None` (not `0.0`) on an I2C failure so
a wedged bus is distinguishable from a genuine due-north reading; the hub holds
the last good heading across a `None`. Self-test: `python sensor_hub.py` →
`SENSOR HUB OK` (covers a failing sensor and a hung poller).

Still inline and still blocking, but sub-millisecond so not worth threading:
`controller.read_pico_lines()` (non-blocking by construction, same buffered-drain
pattern as GPS) and `audio_engine.play()` (already fire-and-forget — it spawns
its own daemon thread, `play()` itself just does an `os.path.exists` and a thread
start).

### RESOLVED — IMU stabilization is now differential, not a common offset
It used to feed pitch into `center_stride_y` and roll into `lateral_roll_offset`,
applying **the same offset to all four legs**. Measured directly: at the maximum
correction values, the change in every foot's Z was **0.0000 cm** — a body
*translation* with zero restoring moment, so no gain would ever have made it work.

`ik_and_gait.attitude_height_offsets(roll_deg, pitch_deg)` now computes a **per-leg**
height change from each hip's position: `dz = gain * (hx*tan(roll) - hy*tan(pitch))`.
Raising the low corners and lowering the high ones is what produces an actual
restoring moment. `build_gait()` feeds this into `center_height_z` per leg. Verified
in the simulator: 15° of simulated roll now produces a measurable left/right foot
height difference; 15° of pitch produces a front/rear difference; zero tilt gives
identical heights across all four legs (as it must).

`gain = 0.6` (damped, not a full correction in one update — avoids overshoot) and
`limit_cm = 4.0` (caps how far one corner can be driven from stand height) are in
`pi5_main.py`; both are guesses that need bench tuning against the real BNO085.
`max_tilt_deg = 30` in the function itself clamps the input before it reaches
`tan()`, which blows up near 90°.

Sign convention: positive roll is taken as right-side-down, positive pitch as
nose-up. **If the BNO085 is mounted with either axis flipped relative to that, the
correction will actively tip the robot the wrong way — check this on the bench
before trusting it, ideally with the robot held up off the ground first.**

### Low-voltage alarm threshold may be unreachable — check which rail the INA219 is on

`pi5_main.LOW_VOLT_THRESHOLD = 4.75` V, compared against `INA219.get_voltage()`.
That is a sensible undervoltage trip for a **5 V regulated rail**, but the BOM
and README describe the INA219 as *battery* telemetry, and the electronics pack
is a **2S LiHV** — roughly 8.7 V full to 6.0 V empty. If it is wired across that
battery, 4.75 V is below fully-flat and `low_battery.wav` can never play; the
alarm is dead code. Decide which it is and set the threshold to match (~6.4 V
for a 2S pack, or leave 4.75 if it really is on the 5 V rail).

There is no longer a current side to this alarm — `MAX_CURRENT_MA` was removed
and the check is voltage-only, because it is unconfirmed whether a shunt is even
in the load path. See *INA219 — voltage-only for now* below for the full state.
Either way this is on the *electronics* supply — nothing monitors the 3S motor
pack, which is the one that actually gets hammered.

Verified correct while checking this, so it does not need re-deriving: config
word `0x399F` decodes to 32 V range / ±320 mV / 12-bit / continuous, calibration
2048 gives a 0.2 mA current LSB matching `raw * 0.2`, and the power LSB is 20×
that, matching `raw * 4.0` mW.

### RESOLVED — an out-of-range target left the motor at its last duty

`JointController.move_to()` returned early — before touching the PWM registers —
when `target_angle` was non-finite or outside ±360°. The guard itself is right
(it is what stops NaN surviving the clamp as full duty), but the bare `return`
meant the joint kept driving at whatever duty the previous call set. On a
saturated PID that is full duty into a stop, held until a good target arrives.

It also left `self.last_time` untouched, so the first good call after a run of
bad ones saw a `dt` inflated by the whole gap and dumped a large `error * dt`
straight into the integrator.

**Fixed:** the guard now zeroes both PWMs (coast), clears `integral` and
`prev_error` so nothing carries across the gap, and advances `last_time`. Still
low-likelihood — `pico_main` range-checks every payload before it reaches the
buffer — but it is now a safe failure rather than a latched one.

### Compass: declination + tilt now handled; hard/soft-iron calibration still not

Fixed:

- **Declination.** `CompassReader(declination_deg=...)` is fed
  `MAGNETIC_DECLINATION_DEG` (pi5_main, currently `-13.0` for northern NJ) and
  added to every reading, so `get_heading()` now returns *true* north to match
  the GPS bearings and Google-Maps coordinates. Edit the constant for your area.
- **Tilt compensation.** `get_heading(roll_deg, pitch_deg)` de-rotates the field
  into the horizontal plane (Honeywell AN3192 form) using the latest IMU
  attitude, which `SensorHub._nav_poll` now passes in. At roll = pitch = 0 it is
  byte-identical to the old `atan2(y, x)`, so there is no regression when level;
  it only removes the per-stride heading wobble when the body tilts.
- **Bad-sample rejection.** Returns `None` (not `0.0`, and not a garbage angle)
  on I2C `OSError`, on the QMC5883L overflow bit, and on an all-`0x0000` /
  all-`0xFFFF` block. Init does a soft reset first and records `configured`.
- **Frozen-heading detection.** `nav_snapshot()` exposes `heading_age` (time
  since the last *good* read — the shared nav poller keeps ticking on GPS alone,
  so `heading` staying non-None can't reveal a dead compass). Under AUTONOMOUS,
  `heading_age > HEADING_MAX_AGE_S` (3 s) makes the robot hold position instead
  of driving on a stale bearing, and drops the `compass` health bit live so the
  dashboard shows the amber "compass offline" banner.

Still open (descoped on purpose):

- **No hard/soft-iron calibration.** Raw `atan2` on a frame full of servo
  magnets and battery current carries a large *heading-dependent* offset that
  declination cannot remove. Needs a "spin 360° and collect min/max" routine
  writing a cal file. Until then, absolute heading accuracy is poor; the closed
  nav loop still converges because `calculate_nav` re-derives the bearing from
  the live GPS every pass and `ARRIVE_RADIUS_M` is 4 m.
- **Axis / sign not bench-verified.** The tilt-comp math assumes x-forward,
  y-right (or the pre-existing frame the old `atan2(y, x)` implied), z-down, with
  the BNO085 roll/pitch signs matching. If a bench heading check ever shows the
  robot turning *away* from a waypoint, the heading runs the wrong way and the
  `atan2` / roll / pitch signs in `CompassReader.get_heading` need flipping.
  (This is a no-op-at-level change, so it did not make anything worse.)

### RESOLVED — autonomous nav no longer drives on a dead sensor

Three related failures, all the same shape as the compass frozen-heading bug:

- **GPS goes silent → frozen fix.** `GPSReader` left `has_fix` / `lat` / `lon`
  latched at their last values when the receiver stopped sending, and the
  `AUTONOMOUS` gate only checked `has_fix` and the *poller* age (which the shared
  GPS+compass poller keeps fresh). Now `GPSReader.fix_t` timestamps the last
  positional GGA, `nav_snapshot()` exposes `fix_age`, and a fix older than
  `GPS_FIX_MAX_AGE_S` (5 s) counts as no fix.
- **No-fix `AUTONOMOUS` walked off blindly.** The "no usable GPS fix" branch
  printed a message but did **not** set `chosen_direction` / `stride_scale`, so
  they fell through carrying the last *manual* steering value at full stride —
  an autonomous robot that lost its fix drove forward in whatever direction the
  slider was last on. It now holds position, like the paused / mission-complete
  / heading-stale branches.
- **Dead sensors reported healthy.** `subsystem_health['gps']` / `['compass']`
  are updated live from the loop now (not just at boot), so a receiver or
  magnetometer that quits mid-run lights the dashboard degrade banner.

### RESOLVED — a camera that fails to open no longer reads as healthy

`USBWebcam.__init__` used to set `self.running = False` and return an object.
`_bring_up()` saw a successful construction, marked the camera up, and
`camera_loop` spun forever on `get_frame()` returning `None` while obstacle
avoidance silently starved. It now `raise`s, so `_bring_up` catches it, the
camera subsystem is marked down (degrade banner), and `camera_loop` returns
immediately — same as every other missing sensor.

### RESOLVED — `port_by_leg` mutated without the serial lock

`register_leg_announcement` inserts into `self.port_by_leg` from the control-loop
thread (a Pico that resets mid-run re-announces on every pass), while the gait
worker reads it via `active_legs()` on its own thread. An insert during the
worker's `sorted(port_by_leg.items())` is a "dict changed size during iteration".
Both sides are under `serial_lock` now, matching what `handle_recovery` and
`request_stop` already did.

### INA219 — voltage-only for now; confirm the wiring

**Needs a bench check on the actual board.** Two unknowns:

1. **What VIN− senses.** `LOW_VOLT_THRESHOLD = 4.75 V` in `pi5_main` suits the
   5 V regulated rail (warn when the buck sags). If VIN− is on the 2S pack
   instead (~6.0–8.4 V LiPo / 6.6–8.7 V LiHV) the alarm can never fire and the
   threshold should be ~6.2–6.6 V. There's a `TODO(hardware)` on the constant.
2. **Whether a shunt is in the load path** across VIN+/VIN−. If the board is
   wired as a plain voltmeter (VIN+/VIN− bridged), `get_current()` /
   `get_power()` are meaningless.

Current state: **only `get_voltage()` is used.** `sensor_hub._power_poll` no
longer calls `get_current()` (it stores `None`), and the `pi5_main` power check
is voltage-only. `INA219.get_current()` / `get_power()` are kept intact but
uncalled — once the shunt path is confirmed, re-enable the one line in
`_power_poll` and restore the current check in `pi5_main`. The config register
(`0x399F` + cal `2048`) assumes ±320 mV / 0.1 Ω = ±3.2 A FSR, so if the INA219
turns out to be on a motor rail that draws more, the current reading would pin
and the (unchecked) overflow bit would set — another reason to verify before
trusting it.

### RESOLVED — two repo files could not run at all

- **`single_leg_test.py` could not import on the Pi.** Line 19 was
  `from InverseKinematics.ik_and_gait import ...`, but the directory is
  `inverse_kinematics`. Linux is case-sensitive, so this was an immediate
  `ModuleNotFoundError` — and the README recommends this file as *the* way to
  test without ROS. Fixed. Still worth knowing it drives the legacy `GaitPath` /
  `direction_angle` steering, not `body_twist_xy_path`, so it is a joint-level
  bench tool and not a preview of how the robot actually walks.
- **`test_pi_quadruped.py` tested an API that no longer exists.** It asserted on
  `controller.current_state` and `RobotState.RECOVERY`, both removed when the
  state machine was split into `current_mode` / `current_activity`, so it failed
  at the first assertion. Updated to the split fields, and it now also asserts
  the thing the split was *for*: that recovery clears the activity and leaves the
  operating mode alone.

### RESOLVED — Pico PID state was not reset when drive is cut

`pico_main`'s `if has_aborted or not powered:` branch zeroes all six PWM
registers but leaves each `JointController`'s `integral`, `prev_error` and
`last_time` untouched. On resume, `dt` is the entire time drive was off.

Measured: after a 120 s Stop, the first `move_to()` put the integrator straight
to its clamp in a single call, because `error * dt` = 20 × 120. Bounded by the
clamp so nothing ran away, but it is the identical stale-`dt` failure mode the
out-of-range guard already fixes (RESOLVED, above).

**Fixed:** `JointController.reset_pid()` drops the integral and derivative state
and restarts the `dt` clock. `pico_main` tracks `drive_was_cut` and calls it once
on the transition back to driving, so it runs on the edge rather than every pass.
Verified: integral 0.040 after a 120 s gap, against 50.0 (the clamp) before.

### RESOLVED — `fsr.py` interrupt helpers could not both be used

`on_touchdown()` and `on_liftoff()` each called `self._pin.irq(...)`, and a Pin
holds only one handler — registering the second silently replaced the first.
Both also passed a `lambda`, which allocates, and MicroPython forbids allocation
inside a hard IRQ, so the handler could fail at the worst possible moment.

Replaced with a single `on_edge(callback, rising=, falling=)` that registers one
bound method (`_on_irq`, no allocation) and reports which edge fired via
`callback(is_touchdown)`. Still unused — `pico_main` polls `.state` — but it is
no longer a trap for whoever wires up interrupt-driven contact next.

### IK clamps unreachable targets silently
`InverseKinematics.calculate` clamps out-of-range law-of-cosines arguments and the
shoulder-to-foot distance instead of reporting that a target cannot be reached. Ask
for z = 55 cm and the foot lands at 52.11 with no exception and no flag, so the
caller cannot tell the difference between "done" and "as close as I could get".

Harmless for the current gait (it uses z = 31–38.5 cm, well inside the 2.47–51.21 cm
annulus) but it will hide mistakes in any future terrain or body-shift work. A
`reachable` flag on the result would fix it; not added because nothing reads it yet.

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

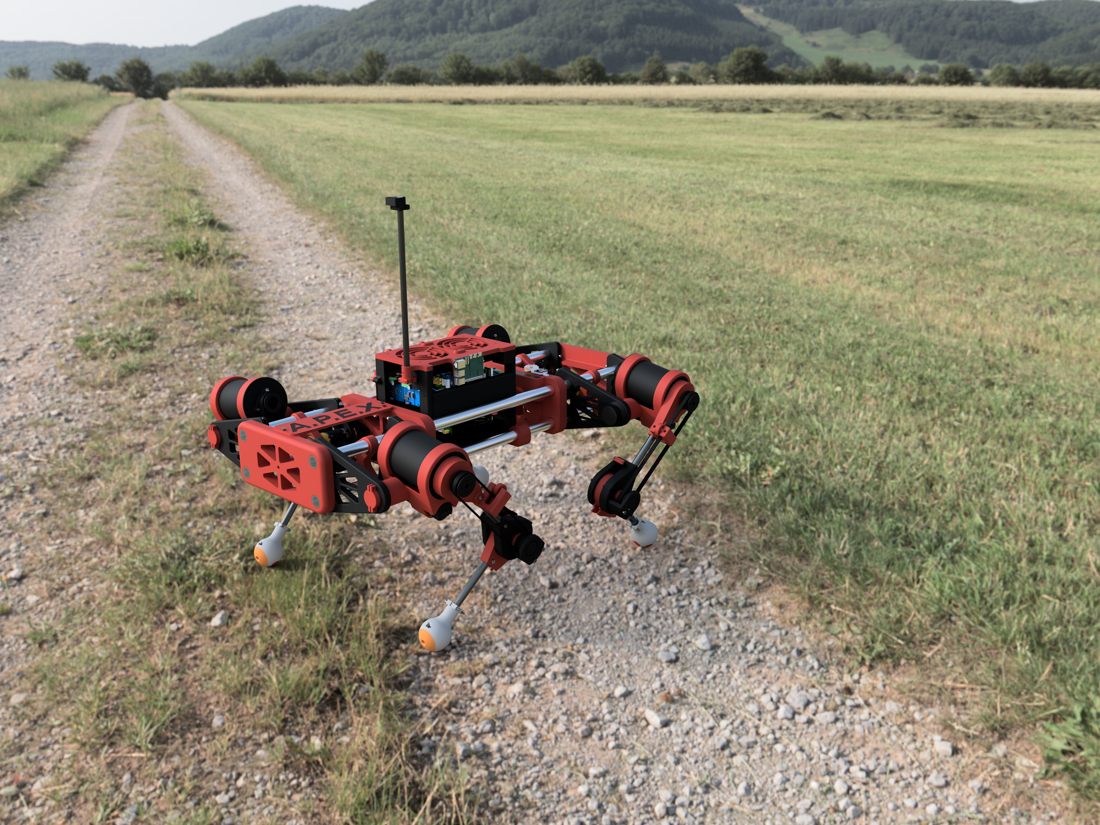
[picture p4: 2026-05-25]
Photos/APEX_in_field.png

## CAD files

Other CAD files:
CAD/APEX Leg V2.2.f3z
CAD/APEX.f3z
CAD/Older Versions/APEX Leg V2.2.f3z
CAD/Older Versions/APEX.f3z
CAD/Older Versions/PCB V1.f3z
CAD/PCB V1.f3z

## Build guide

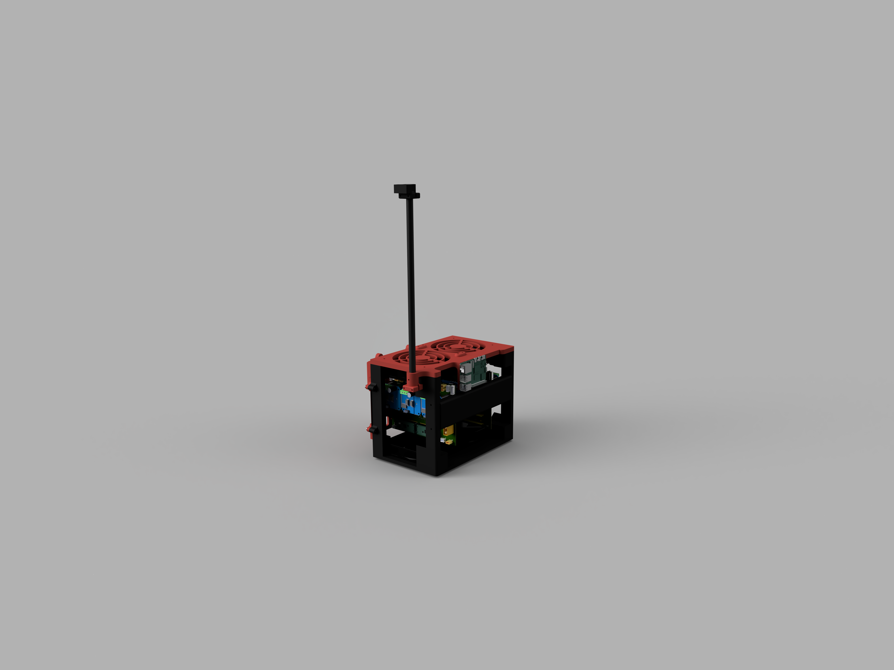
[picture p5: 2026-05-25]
Photos/APEX_electronics_assembly_isometric_view.png

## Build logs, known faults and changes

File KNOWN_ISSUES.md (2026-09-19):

# Known Issues

Defects found during a full read of the control path that were **not** fixed, with
why they were deferred, plus the manual configuration steps the fixes introduced.
Ordered by how badly they bite. Fixed defects are kept here too, marked
**RESOLVED**, as a record of what broke and why the fix works — see git history
for the actual diffs.

## Read this first

The two-minute version. Full detail is one click away on each line.

- **[IMU roll/pitch signs are unverified](#imu-banner)** — if either axis reads
  backwards, self-levelling pushes the tilt *further* over instead of correcting
  it. [Bench-check it](#verify-the-imu-roll-pitch-signs-do-this-one-first) before
  the first unsupported walk — do this one first.
- **[Re-flash all 4 Picos](#reflash-banner)** — seven firmware fixes are sitting
  in `Code/Pico/` and none of them exist on the robot until it's reflashed.
- **[Set `LEG_ID` on each Pico](#set-leg-id-on-each-pico)** — all four boards
  currently ship as `0`.
- **[Set `FSR_PIN` before wiring the foot sensors](#resolved-fsr-abort-fired-on-the-first-swing-step-of-every-leg)** — defaults to 16, must match each leg's actual wiring.
- **[Verify the `reverse` flags during an actual turn](#set-the-left-right-reverse-flags-now-matters-for-turning-verify-it)** — wrong polarity here now steers the wrong way, not just at boot.
- **[PID `kp = 0.8` still needs bench tuning](#pid-kp-still-needs-bench-tuning-windup-ruled-out-kd-fixed)** — simulation favors a softer gain, but the sim has no gravity or load to fight.
- **[Confirm which rail the INA219 is on](#low-voltage-alarm-threshold-may-be-unreachable-check-which-rail-the-ina219-is-on)** — the low-voltage alarm may be watching a rail that never drops.
- **[IK clamps unreachable targets silently](#ik-clamps-unreachable-targets-silently)** — a bad command doesn't error, it just quietly clips.
- **[Obstacle avoidance has never run on real hardware](#obstacle-avoidance-built-and-simulated-never-run-on-hardware)** — simulated and unit-tested only; tune thresholds on the bench first.
- **[Compass hard/soft-iron calibration still isn't done](#compass-declination-tilt-now-handled-hard-soft-iron-calibration-still-not)** — declination and tilt compensation are in, calibration against local magnetic interference is not.
- **[Per-motor current sensing is planned, not built](#current-sensing-banner)** — the BTS7960 `IS` pins could catch a jammed joint or collision; nothing reads them yet.
- **[Swing clearance is 4.76 cm, not the nominal 5.0](#swing-clearance-is-4-76-cm-not-the-nominal-5-0)** — small margin, worth knowing before assuming ground clearance.
- **[Encoder zero must match `HOME_POSE`](#encoder-zero-must-match-home-pose-this-is-what-homing-top-of-doc-is-for)** — that's what the manual homing step (below) is for.
- **[Protocol gaps accepted for now](#protocol-gaps-accepted-for-now)** — known wire-protocol rough edges that aren't worth fixing yet.

<details>
<summary><strong>Full section index</strong> (every heading in this document)</summary>

- [RESOLVED — receiving a gait frame froze the gait (the robot would not walk)](#resolved-receiving-a-gait-frame-froze-the-gait-the-robot-would-not-walk)
- [RESOLVED — pressing Go yanked three planted feet sideways](#resolved-pressing-go-yanked-three-planted-feet-sideways)
- [RESOLVED — the Pico threw away every Stand and Go ramp (robot could not stand)](#resolved-the-pico-threw-away-every-stand-and-go-ramp-robot-could-not-stand)
- [RESOLVED — every gait re-send teleported the feet (25.6° / 17.6 cm, full duty)](#resolved-every-gait-re-send-teleported-the-feet-25-6-17-6-cm-full-duty)
- [RESOLVED — STAND while walking commanded a 68.6 cm lurch](#resolved-stand-while-walking-commanded-a-68-6-cm-lurch)
- [RESOLVED — one InverseKinematics shared across threads returned wrong angles](#resolved-one-inversekinematics-shared-across-threads-returned-wrong-angles)
- [Swing clearance is 4.76 cm, not the nominal 5.0](#swing-clearance-is-4-76-cm-not-the-nominal-5-0)
- [Not a defect: stance y quantisation](#not-a-defect-stance-y-quantisation)
- [Obstacle avoidance — built and simulated, never run on hardware](#obstacle-avoidance-built-and-simulated-never-run-on-hardware)
  - [Tune these on the bench before trusting it outdoors](#tune-these-on-the-bench-before-trusting-it-outdoors)
  - [RESOLVED — an absolute depth threshold read the ground as an obstacle](#resolved-an-absolute-depth-threshold-read-the-ground-as-an-obstacle)
  - [Known limits of the approach itself](#known-limits-of-the-approach-itself)
  - [Validated against real ground-robot imagery](#validated-against-real-ground-robot-imagery)
  - [First hardware session should be, in order](#first-hardware-session-should-be-in-order)
- [PLANNED — migrate ground-contact sensing from FSR to current sensing](#planned-migrate-ground-contact-sensing-from-fsr-to-current-sensing)
- [Homing — a manual step you have to do, before every power-on](#homing-a-manual-step-you-have-to-do-before-every-power-on)
  - [RESOLVED — Home button, one leg at a time](#resolved-home-button-one-leg-at-a-time)
  - [RESOLVED — boot no longer moves the legs](#resolved-boot-no-longer-moves-the-legs)
  - [RESOLVED — smooth ramps instead of one big jump: Stand and Go](#resolved-smooth-ramps-instead-of-one-big-jump-stand-and-go)
  - [RESOLVED — Stop](#resolved-stop)
  - [Bug caught while building Stand/Go, not previously exercised](#bug-caught-while-building-stand-go-not-previously-exercised)
  - [Still open, and worth deciding before any of this is trusted](#still-open-and-worth-deciding-before-any-of-this-is-trusted)
- [Before you walk it](#before-you-walk-it)
  - [Set LEG_ID on each Pico](#set-leg-id-on-each-pico)
  - [Set the left/right `reverse` flags — now matters for turning, verify it](#set-the-left-right-reverse-flags-now-matters-for-turning-verify-it)
  - [Verify the IMU roll/pitch signs — do this one first](#verify-the-imu-roll-pitch-signs-do-this-one-first)
  - [Front/rear mirroring is handled in software — verified](#front-rear-mirroring-is-handled-in-software-verified)
  - [Body geometry (set — recorded here because it lives nowhere else)](#body-geometry-set-recorded-here-because-it-lives-nowhere-else)
- [Debug tool: per-leg deactivation](#debug-tool-per-leg-deactivation)
- [Will make the robot fall over](#will-make-the-robot-fall-over)
  - [OPEN — the IMU roll/pitch signs are unverified, and a wrong one is positive feedback](#open-the-imu-roll-pitch-signs-are-unverified-and-a-wrong-one-is-positive-feedback)
  - [RESOLVED — body shift, phased with the lift sequence](#resolved-body-shift-phased-with-the-lift-sequence)
  - [RESOLVED — `height2` (stance push) set to 0](#resolved-height2-stance-push-set-to-0)
  - [RESOLVED — `STEP_TICK_MS` raised 20 → 40 ms](#resolved-step-tick-ms-raised-20-40-ms)
- [Will misbehave](#will-misbehave)
  - [RESOLVED — `current_state` conflated operating mode with transient activity](#resolved-current-state-conflated-operating-mode-with-transient-activity)
  - [RESOLVED — one leg recovers while the other three keep walking: policy is "go to neutral"](#resolved-one-leg-recovers-while-the-other-three-keep-walking-policy-is-go-to-neutral)
  - [RESOLVED — steering is now a body twist (yaw), not differential stride](#resolved-steering-is-now-a-body-twist-yaw-not-differential-stride)
  - [RESOLVED — mission end now holds position; route is editable from the dashboard](#resolved-mission-end-now-holds-position-route-is-editable-from-the-dashboard)
  - [RESOLVED — blocking sensor reads moved off the control loop](#resolved-blocking-sensor-reads-moved-off-the-control-loop)
  - [RESOLVED — IMU stabilization is now differential, not a common offset](#resolved-imu-stabilization-is-now-differential-not-a-common-offset)
  - [Low-voltage alarm threshold may be unreachable — check which rail the INA219 is on](#low-voltage-alarm-threshold-may-be-unreachable-check-which-rail-the-ina219-is-on)
  - [RESOLVED — an out-of-range target left the motor at its last duty](#resolved-an-out-of-range-target-left-the-motor-at-its-last-duty)
  - [Compass: declination + tilt now handled; hard/soft-iron calibration still not](#compass-declination-tilt-now-handled-hard-soft-iron-calibration-still-not)
  - [RESOLVED — autonomous nav no longer drives on a dead sensor](#resolved-autonomous-nav-no-longer-drives-on-a-dead-sensor)
  - [RESOLVED — a camera that fails to open no longer reads as healthy](#resolved-a-camera-that-fails-to-open-no-longer-reads-as-healthy)
  - [RESOLVED — `port_by_leg` mutated without the serial lock](#resolved-port-by-leg-mutated-without-the-serial-lock)
  - [INA219 — voltage-only for now; confirm the wiring](#ina219-voltage-only-for-now-confirm-the-wiring)
  - [RESOLVED — two repo files could not run at all](#resolved-two-repo-files-could-not-run-at-all)
  - [RESOLVED — Pico PID state was not reset when drive is cut](#resolved-pico-pid-state-was-not-reset-when-drive-is-cut)
  - [RESOLVED — `fsr.py` interrupt helpers could not both be used](#resolved-fsr-py-interrupt-helpers-could-not-both-be-used)
  - [IK clamps unreachable targets silently](#ik-clamps-unreachable-targets-silently)
  - [RESOLVED — a blocked leg sat at 100% PWM indefinitely (needs a Pico reflash)](#resolved-a-blocked-leg-sat-at-100-pwm-indefinitely-needs-a-pico-reflash)
  - [RESOLVED — FSR abort fired on the FIRST swing step of every leg](#resolved-fsr-abort-fired-on-the-first-swing-step-of-every-leg)
  - [PID: `kp` still needs bench tuning (windup ruled out, `kd` fixed)](#pid-kp-still-needs-bench-tuning-windup-ruled-out-kd-fixed)
  - [Minor: stale target for one tick](#minor-stale-target-for-one-tick)
- [Verify on hardware](#verify-on-hardware)
  - [RESOLVED — BNO085 constant names, and boot no longer dies on a bad hardware init](#resolved-bno085-constant-names-and-boot-no-longer-dies-on-a-bad-hardware-init)
  - [RESOLVED — BTS7960 dual enable confirmed tied together on the PCB](#resolved-bts7960-dual-enable-confirmed-tied-together-on-the-pcb)
  - [Encoder zero must match HOME_POSE — this is what homing (top of doc) is for](#encoder-zero-must-match-home-pose-this-is-what-homing-top-of-doc-is-for)
  - [Dead branch in `imu.py`](#dead-branch-in-imu-py)
- [Structural notes from the full review (no defect, worth knowing)](#structural-notes-from-the-full-review-no-defect-worth-knowing)
  - [The IK cannot flip the knee to the other solution — verified](#the-ik-cannot-flip-the-knee-to-the-other-solution-verified)
  - [Gait quality — one leg up, three legs pushing; turning really does use hip roll](#gait-quality-one-leg-up-three-legs-pushing-turning-really-does-use-hip-roll)
  - [What `reverse` does and does not control](#what-reverse-does-and-does-not-control)
- [Protocol gaps (accepted for now)](#protocol-gaps-accepted-for-now)

</details>

---

> **RE-FLASH THE PICOS BEFORE THE NEXT POWERED TEST.** Seven firmware defects
> have been fixed in `Code/Pico/` and none of them reach the robot until it is
> reflashed — a Pi running the new code against old firmware still cannot stand,
> and still will not walk:
>
> - the Stand and Go ramps were silently discarded (the robot could not stand at all)
> - **receiving a frame froze the gait — measured 0 steps in 20 s at any re-send
>   faster than 69 ms, i.e. the robot stands still while the dashboard says WALKING**
> - the step clock's cadence tracked loop jitter instead of being a fixed 40 ms
> - every gait re-send restarted the cycle from step 0, slamming the feet
> - a blocked joint held 100% PWM forever, with nothing to stop it
> - the FSR abort would have fired on every leg's first swing step
> - PID state survived a Stop, saturating the integrator on resume
>
> Also **set `LEG_ID`** (all four boards currently ship as `0`) and **`FSR_PIN`**
> before wiring the foot sensors. Each is written up in its own section below.

> **VERIFY THE IMU ROLL/PITCH SIGNS BEFORE THE FIRST UNSUPPORTED WALK.** Body
> levelling assumes right-side-down is a positive roll and nose-up a positive
> pitch. Whether the BNO085 actually reads that way depends on how it is bolted
> in, nothing in the code or the simulator can detect it, and if either axis is
> inverted the correction is **positive feedback** — it grows the tilt to 8.6° of
> self-inflicted lean against a 2.4 cm stability margin. Two-minute bench check in
> *Will make the robot fall over → OPEN — the IMU roll/pitch signs are unverified*.

> **TO BUILD: per-motor current sensing off the BTS7960 IS pins.**
> **Not implemented — no code for this exists yet.**
>
> Every BTS7960 already has a built-in current-sense output (`R_IS` / `L_IS`, a
> current mirror at roughly 1/8500 of load current). Feeding those into the Pico
> means each leg can watch what its own three motors are actually drawing, and a
> current spike = **the joint met resistance it shouldn't have** — the robot walked
> into something, a foot jammed, a link is binding. That's the trigger to abort the
> gait and drop into `handle_recovery` instead of grinding the motor against
> whatever stopped it.

**Verify the whole control path without hardware:**

```bash
cd Code/Pi5/inverse_kinematics && python quadruped_sim.py --report   # gait verdict
cd Code/Pi5 && python vision_obstacle.py                             # avoidance planner
cd Code/Pi5 && python sensor_hub.py                                  # sensor pollers
```

**Verify the gait before touching hardware:**

```bash
cd Code/Pi5/inverse_kinematics
python quadruped_sim.py --report      # numeric verdict, no dependencies
python quadruped_sim.py               # 3D animation, needs matplotlib
```

`matplotlib` is not currently installed (`pip install matplotlib`), which also means
`gait_testing2.py` and `gait_testing3.py` cannot run as-is. `--report` works without
it.

---

## RESOLVED — receiving a gait frame froze the gait (the robot would not walk)

**The worst defect found so far. It stopped the robot walking at all, silently.**
Needs a Pico reflash *and* the Pi-side change.

A gait frame is `2 + 20*16 + 16 = 338` bytes; at 115200 8N1 that is **29.3 ms of
wire time** per port. Two things then conspired on the Pico:

1. `gait_buffer` was cleared at `START_MARKER` and refilled in place, and step 3
   was gated on `not is_receiving` — so for the whole 29.3 ms the leg had nothing
   to step through and simply held its last target;
2. `last_step_time` was reset to *now* on **every** end marker, restarting the
   40 ms tick from zero each time a frame landed.

So a frame had to arrive, and then a further 40 ms of silence had to pass, before
the gait advanced by one step. The Pi's re-send trigger (steering moved >5°, tilt
>1.5°, stride >0.05) is evaluated every ~10 ms and **nothing rate-limited it** —
during a turn, or on any ground that moves the IMU, the Pi re-sent far faster than
that. Measured in `wire_timing.py`, replaying the real parser logic against real
baud timing:

| Pi re-sends every | gait steps in 20 s | vs. commanded |
|---|---|---|
| 20 ms | **0** | 0% — *and frames truncated mid-flight* |
| 50 ms | **0** | 0% |
| 69 ms | **0** | 0% |
| 100 ms | 200 | 40% |
| 250 ms | 400 | 80% |
| never | 499 | 100% |

Below ~30 ms it got worse still: the worker's own send loop is ~22 ms against
29.3 ms of wire time, so it began the next frame while the previous was still
draining and `reset_output_buffer()` — `tcflush(TCOFLUSH)` on POSIX — **discarded
the tail**, end marker included. The Pico then sat in `is_receiving` forever,
eating the next `START_MARKER` as payload, until enough garbage arrived to trip
`MAX_GAIT_STEPS`.

Three fixes, and the gait now runs at 498–499 steps / 20 s at *every* re-send rate:

- **Pico — staging buffer.** Frames land in `rx_buffer` and are swapped into
  `gait_buffer` only once their end marker is parsed. Step 3 lost its
  `not is_receiving` condition, so the leg keeps walking the last complete cycle
  while the next one is on the wire. A truncated or desynced frame now discards
  only the staged copy, so it can no longer freeze a leg either.
- **Pico — `RESYNC_INTERVAL_MS = 5000`.** The step clock is re-aligned to a frame
  boundary at most every 5 s instead of on every frame. Between re-syncs the
  boards free-run on their crystals: at a worst-case 100 ppm spread that is 0.5 ms
  of drift over 5 s, against a 40 ms tick and the one-tick guard band between each
  leg's swing window. Cost is at most one truncated tick per 5 s, under 1% of
  walking speed. A genuinely new trajectory (ramp, recovery, a cycle of a
  different length) still re-syncs immediately, which is the moment it matters.
- **Pi — `MIN_GAIT_RESEND_S = 0.10` and `_drain()`.** The control loop will not
  push frames faster than 10 Hz, and the worker now `flush()`es each port before
  the next `reset_output_buffer()` can run, which makes the truncation race
  impossible rather than merely unlikely. Skipping a re-send loses nothing:
  `last_sent_*` is only updated when a frame actually goes out, so the delta stays
  tripped and the update leaves on the next eligible pass.

Also fixed alongside: the tick advanced by `last_step_time = ticks_ms()`, making
the real cadence 40 ms *plus* however long that pass took. Harmless while every
end marker re-synced the clock; not harmless once re-syncs are 5 s apart. It now
advances by exactly `STEP_TICK_MS`, snapping forward only if it has fallen more
than a full tick behind.

---

## RESOLVED — pressing Go yanked three planted feet sideways

`engage_walking()` ramped every leg from the stand pose to `all_angles[0]`, then
started the cyclic walk. But `_gait_serial_worker` rotates each leg's buffer by
`phase_offsets()` — buffer index `j` for leg L is global tick `j - offset_L`,
which is exactly what `apply_body_shift()` assumes — so leg L's first *commanded*
frame is `all_angles[offsets[L]][L]`, not `all_angles[0][L]`.

Ramping all four to index 0 put them at four different points of the cycle at
once, a configuration the body never actually holds, and the first cyclic tick
then snapped each leg to its real phase:

| leg | phase offset | joint jump | foot moved | in one 40 ms tick |
|---|---|---|---|---|
| Front-Left | 0 | 0.00° | 0.00 cm | correct by luck — its offset is 0 |
| Front-Right | 10 | 10.95° | 7.11 cm | |
| Rear-Right | 15 | 11.42° | 6.93 cm | |
| Rear-Left | 5 | **21.45°** | **13.15 cm** | |

Normal stance travel is 0.67 cm per tick and the joint-rate budget behind
`STEP_TICK_MS = 40` is 9.4°/tick, so this was ~20× over on both counts. All four
feet are planted at that instant (swing is local indices 1–4, not 0), so nothing
was airborne to absorb it — the three legs fought each other through the frame at
full duty, either scrubbing the feet or lurching the body. This is precisely the
slam the whole Home → Stand → Go sequence exists to prevent, and it fired on the
first walking command every single time.

`gait_entry_pose()` now returns each leg's own phase-shifted entry frame and the
ramp targets that. Verified: worst residual jump 0.00°, and the first cyclic tick
is 9.26° — inside budget.

---

## RESOLVED — the Pico threw away every Stand and Go ramp (robot could not stand)

**This one stopped the robot working at all, and needs a Pico reflash to fix.**

`pico_main.MAX_GAIT_STEPS` was **32**. It exists as a desync guard — an overlong
frame means the byte stream lost sync mid-payload, and the cap stops the buffer
growing until `MemoryError`:

```python
gait_buffer.append(parts)
if len(gait_buffer) > MAX_GAIT_STEPS:
    gait_buffer = []          # the WHOLE frame is thrown away
    is_receiving = False
```

But the largest frame the Pi legitimately sends is the Stand/Go Cartesian ramp,
and `build_ramp(steps=40)` → `cartesian_ramp` → `range(steps + 1)` = **41
frames**. Every STAND and every GO therefore hit the guard at frame 33, had the
whole buffer discarded, and the remaining 8 frames plus the end marker were
rescanned as raw bytes looking for a start marker. The leg never left its homed
pose. Nothing logged it — from the Pi's side the frame went out fine.

The 20-frame walking gait, the 21-frame recovery path and the 2-frame
`settle_to_stand` were all under the cap, which is why the bug hid: everything
except the two ramps worked.

**Fixed** by raising `MAX_GAIT_STEPS` to **48** (still a desync guard, now above
every legitimate frame) and adding `PICO_MAX_FRAMES = 48` on the Pi, which
`send_entire_gait()` checks — it now logs and returns `False` rather than
believing an oversized frame was sent, and `request_stand` / `engage_walking` /
`settle_to_stand` propagate that failure instead of setting `standing = True`
regardless. Verified by replaying the real wire bytes through a copy of the
Pico's parser: the 41-frame ramp is accepted and ends holding the stand pose.

---

## RESOLVED — every gait re-send teleported the feet (25.6° / 17.6 cm, full duty)

Also needs the Pico reflash. The Pi rebuilds and re-sends the entire gait
whenever the steering command moves >5°, the IMU tilt moves >1.5°, or the
avoidance stride changes — which in normal walking is often. The Pico's
end-marker handler did:

```python
current_step_index = 0      # restart the cycle
```

So a foot that was mid-stance was told, in one 40 ms tick, to be at the start of
swing instead. That is a phase jump, not a geometry change, and it is large:

| re-send trigger | old (restart at 0) | now (phase kept) |
|---|---|---|
| straight → hard turn | 25.6° / 17.6 cm | **7.1° / 4.2 cm** |
| straight → 45° arc | 20.5° / 12.8 cm | **7.6° / 4.6 cm** |
| walk → march in place | 14.5° / 5.0 cm | **8.9° / 5.0 cm** |
| IMU tilt nudge only | 21.5° / 13.1 cm | **0.0° / 0.00 cm** |

At `kp = 0.8` (saturating above 1.25°) all of the left column is a full-duty slam
— the same failure class as the STAND lurch below, but happening several times a
second while walking rather than once on a button press.

**Fixed** by keeping the buffer index across a re-send *of the same walking
cycle* — same length, both cyclic — and resetting to 0 only for a genuinely new
trajectory (a one-shot ramp, or a cycle of a different length, which must run
from its first entry). `last_step_time` is still reset on every frame, which is
worth keeping: all four boards get their end marker within a few ms of each
other, so it re-aligns the 40 ms tick across legs and stops them free-running
apart. Verified in the wire simulation: all four legs keep the same index across
a re-send and exactly one leg is still airborne immediately after.

Note this is also *safer* for phase than the old behaviour. Previously, if one
leg missed a frame, the three that received it reset to 0 while the fourth kept
counting — a real desync. Now a leg that misses a frame simply keeps its place.

---

## RESOLVED — STAND while walking commanded a 68.6 cm lurch

Found during a full-codebase review, not previously exercised. `request_stand()`
always ramped from `HOME_POSE`, and **nothing anywhere refused it while the robot
was walking** — not the dashboard (`standBtn` was gated only on all-legs-homed),
not the `/stand` route, not the controller. Pressing STAND mid-walk therefore
commanded step 0 of a HOME_POSE ramp — roll 90°, knee 180°, legs straight out —
while the legs were actually near the gait pose:

| | roll | pitch | knee | foot |
|---|---|---|---|---|
| walking gait pose | −15.55° | +44.44° | 85.11° | — |
| what STAND commanded | +90.00° | 0.00° | 180.00° | — |
| instantaneous error | **+105.6°** | −44.4° | +94.9° | **68.6 cm** |

`kp = 0.8` saturates above 1.25° of error, so that is full duty on every joint:
precisely the slam the whole Home → Stand → Go sequence exists to prevent.

**Fixed by making STAND mean the right thing in both states.** From rest it is
still the Cartesian ramp out of HOME_POSE. While walking it now calls the new
`settle_to_stand()`, a direct one-shot move of all four legs to `stand_pose` —
the same 2-entry buffer `handle_recovery` already sends the non-aborting legs,
and accepted there for the same reason. Measured worst case from *any* walking
gait pose (15 cm steering stride, body shift on) is **16.3° at a joint / 9.2 cm
at the foot**, against 105.6° / 68.6 cm before.

Side effect worth knowing: this is the first way to halt a robot that is on its
feet without dropping it. STOP cuts holding torque and lets it sag; STAND now
stops the walk and holds the stance powered. The dashboard says so.

Not a full fix for the missing zero-velocity state (see "No stop command
mid-turn" below) — there is still no "keep walking forward at 0 speed".

---

## RESOLVED — one InverseKinematics shared across threads returned wrong angles

`calculate()` stored its answer on the engine (`self.roll/pitch/knee`) and
returned `self`, so the caller read the angles off shared mutable state *after*
the call returned. `pi5_main` has a single `self.ik_engine`, used from:

- the main control loop — `build_gait()` → `GaitIK` → `calculate()`
- ROS executor threads — `stand_callback`/`go_callback` → `build_ramp()` →
  `cartesian_ramp()` → `calculate()`

Those genuinely overlap (the STAND-while-walking path above is exactly such a
case), and when they do, one thread reads the other thread's joint targets —
which then go straight to a motor. Measured with the GIL switch interval forced
low: **60% of solves corrupted** (24066 of 40000). At the default 5 ms switch
interval it is rare rather than impossible, which is the worst kind of bug.

**Fixed:** `calculate()` now returns an `IKSolution` — a small `__slots__`
object carrying its own roll/pitch/knee — and every intermediate in the solve is
a local. The engine holds only the segment lengths, which are read-only after
construction, so it is safe to share. Attribute names are unchanged, so all four
call sites needed no edit. Re-measured after the fix: **0 of 40000 corrupted.**

Related and also fixed: `request_stand()` and `engage_walking()` were writing
`self.standing` / `self.walking_enabled` without holding `serial_lock`, while
`publish_homing_status()` reads them under it.

---

## Swing clearance is 4.76 cm, not the nominal 5.0

`SWING_HEIGHT = 5.0` is the *continuous* peak of `h1·sin(πs)`, but the swing is
sampled at only 5 points — `s = 0, 0.2, 0.4, 0.6, 0.8` — which never lands on
the `s = 0.5` peak. The highest commanded lift is `5.0·sin(0.4π) = 4.755 cm`.

This matters because it appears in a safety argument: the PID tuning section
below reasons that 9.4° of peak tracking error is "~4 cm at the foot, against
5 cm of commanded swing clearance". The real figure is **4.76 cm**, so the
margin is 0.76 cm rather than 1.0 — about 25% thinner than stated. Still
positive, still needs the bench check that section already asks for.

Raising the swing sample count (a larger `num_steps`, or a finer swing fraction)
would both recover the nominal clearance and soften the liftoff/touchdown corner
that drives the peak joint rate — see `STEP_TICK_MS` below, which wants the same
thing for a different reason.

---

## Not a defect: stance y quantisation

Recorded because it looks like one. `GaitPath.generate_path` rounds each
coordinate to 2 dp, so consecutive stance steps differ by −0.66 or −0.67 cm
rather than a constant −0.667. The underlying formula is exactly linear
(verified: unrounded deltas are a single value); the variation is 0.005 cm of
rounding, 0.05 mm at the foot. The elliptical-stance scrub the design
deliberately rejects is 0.85 cm/tick — **170× larger**. Nothing to do here.

---

## Obstacle avoidance — built and simulated, never run on hardware

`vision_obstacle.py` plus the dashboard toggle. The planner logic is verified
(`python vision_obstacle.py` runs a self-test; a closed-loop sim against the real
`Navigator` showed obstacles struck by 0.95 m with avoidance off cleared by
0.25–0.50 m with it on, no oscillation). **None of the perception side has been
checked against a real camera on the real robot**, and several numbers are
educated guesses until it is.

### Tune these on the bench before trusting it outdoors

- **`ROI_TOP` / `ROI_BOTTOM` (0.45 / 0.95).** Which band of the frame counts as
  "the ground ahead". Depends entirely on where the camera is physically mounted
  and at what angle — a guess until checked against a real still. Too high and it
  reads the sky as clear; too low and it stares at the robot's own nose. Turn
  avoidance on and look at the overlay on the dashboard feed.
- **`OBSTACLE_MARGIN` (0.12).** How much nearer than its own row's ground a pixel
  must read before it counts. Measured insensitive between 0.05 and 0.25 on the
  synthetic scenes, so it is not a knife edge, but it has never met real terrain
  texture. Raise it if grass or gravel trips it, lower it if low obstacles slip
  through. (This replaced an absolute `NEAR_THRESH` — see below.)
- **`FLAT_GRADIENT_MIN` (0.10).** Only fires for a column with no near/far
  contrast at all, i.e. something filling the view. A camera angled further down
  sees less depth range in the band, which shrinks every column's gradient and
  makes false "blocked" more likely — check this once the mount is final.
  Raising it halts more readily, which is the safe direction.
- **`FOV_DEG` (60.0).** Assumed, not measured. Only scales bin index → steering
  angle, so an error here makes turns consistently too shallow or too sharp
  rather than breaking detection.
- **`CLEAR_HOLD_S` (20.0).** How long to drive straight after the obstacle leaves
  view before handing steering back to the navigator. This is the number that
  decides clearing vs. grazing — see the comment on it for the swept data. It is
  a time standing in for a distance because there is no odometry, so it is only
  correct at the assumed ~10 cm/s avoidance speed. **If `STEP_TICK_MS` or the
  base stride changes, this needs re-deriving.**

### RESOLVED — an absolute depth threshold read the ground as an obstacle

Found on a real capture: a person standing in the middle of an otherwise clear
path, with both sides plainly open, reported **fully blocked**. The depth model
was fine — the figure was cleanly segmented — the costmap was wrong.

For a forward-facing camera on flat ground, the distance to the ground at image
row `r` goes as `1/(r - horizon)`, so the inverse depth the model emits ramps
smoothly from far at the top of the frame to near at the bottom. The bottom of
the ROI is therefore *always* near: it is the ground half a metre in front of the
feet. `NEAR_THRESH = 0.55` flagged that ground everywhere. Reproduced on a
synthetic scene built from the flat-ground equation: **bare open ground scored
0.42 in every bin** against a 0.25 block threshold.

**Fixed** by making detection ground-relative: a pixel is an obstacle when it
reads `OBSTACLE_MARGIN` nearer than that row's own `GROUND_REF_PCT` percentile.
An upright object occupies rows that would otherwise show ground far away, so it
stands out sharply. The reference percentile sits below the median deliberately,
so a wide object cannot drag it up to its own depth and hide itself. A separate
per-bin flat-gradient test catches the one thing the relative test cannot see —
something filling a column top to bottom, leaving no contrast to find.

| scene | before | after |
|---|---|---|
| open ground | `#########` | `.........` |
| figure dead centre | `#########` | `....#....` |
| figure on the right | `#########` | `.......#.` |
| wall filling the view | `#########` | `#########` |

A useful property that fell out of it: because the reference comes from the row
itself, a **uniform slope shifts the whole row together and is not flagged**.
Only localised protrusions are, which is what you want on terrain.

These four scenes are now a regression test in `python vision_obstacle.py`, and
the tuning notebook imports the module rather than keeping its own copy of the
pipeline — the two had already diverged once.

### Known limits of the approach itself

- **Monocular depth is relative, not metric.** No true distances, and the scale
  shifts frame to frame. Fine for "something bulky is close", weak for judging
  gap widths.
- **Drop-offs and holes read as *farther* than the ground, never nearer, so the
  detector cannot flag them at all.** This is inherent to the method, not a
  tuning problem: the test asks "is anything closer than the ground should be",
  and a hole is the opposite. The FSR / `ABORTED` recovery path is the only
  backstop, and it only fires on contact.
- **Body width is handled by a fixed angle, but the correct angle depends on
  range.** What has to fit through a gap is ~72 cm (53 cm hip spacing plus the
  abductor sticking out ~9.65 cm each side — *not* the 53 cm `BODY_WIDTH_CM`).
  That subtends 71.7° at 0.5 m but only 20.5° at 2 m — 10.8 bins down to 3.1 —
  and the costmap has no depth axis to tell those apart, since the ROI band
  flattens roughly 0.5–2 m into one row of bins. `CORRIDOR_BINS=3` plus
  `INFLATE_BINS=1` enforces a flat 33.3°, which matches the true width only
  beyond **~1.2 m**; nearer than that it under-provisions on paper, and relies
  on a close obstacle filling enough bins to trip `BLOCKED` instead. Fixing this
  properly needs a range-resolved costmap (split the ROI into near/far rows and
  require a wider corridor in the near row), not a bigger constant — raising
  `CORRIDOR_BINS` to 5 demands 46.7° of a 60° view and leaves almost nothing
  passable.
- **Thin obstacles are unreliable.** Table legs and wires are close to the
  resolution limit at `INPUT_SIZE = 266` and may not survive the bin averaging.
- **No reverse.** Steering is a body yaw now (see the steering entry below), so
  the robot *can* spin in place — `ESCAPE` and a hard turn command both do — but
  it still cannot walk backward. A robot nose-first in a dead end can rotate to
  face out, which the old differential steering could not do, but if it is
  wedged it still needs a human.
- **`BLOCKED` halts by setting stride to 0**, which makes the feet lift and land
  in the same spot — it keeps standing and stays IMU-levelled. This is
  deliberately *not* the dashboard STOP, which cuts holding torque and would let
  a standing robot sag. Verified: `GaitPath` with `length=0` gives all feet
  `y = 0.0` with 4 airborne steps still in the cycle.
- **Fails open, not closed.** A stale costmap (camera died, worker stalled,
  older than `STALE_AFTER_S`) drops back to normal walking rather than halting.
  That is the right call for a slow robot with a human nearby, but it does mean
  a silently dead camera looks like "avoidance is on and the path is clear".
  Watch the dashboard state readout.
- **CPU contention is unmeasured.** Inference is capped at
  `cpu_count - 2` threads to leave room for the 100 Hz control loop and the four
  serial writers, but the effect on control-loop timing has not been measured on
  a loaded Pi 5.

### Validated against real ground-robot imagery

The tuning notebook's Test 1 now runs eight photographs taken from actual ground
robots — camera low, pointed straight ahead, ground plane filling the lower
frame — rather than scenic stills. Two results are worth carrying forward:

- **`INFLATE_BINS = 1` is load-bearing.** Dropping it to 0 makes an indoor
  corridor with a wall down each side report CLEAR. Confirmed on real imagery,
  not just simulation.
- **A trail that looks walkable reports BLOCKED, correctly.** Its clear gap
  measures 26.7°, which against the 72 cm body is 47 cm at 1 m, 71 cm at 1.5 m,
  95 cm at 2 m — genuinely too tight near, fine further out. A good illustration
  of the range-dependence limitation above: the costmap has no depth axis, so it
  cannot express "tight now, fine in a metre" and halts instead.
- **A low cardboard box on paving, several metres out, is missed.** Too few
  pixels clear `OBSTACLE_MARGIN` for its bin to reach `BLOCK_FRAC`. It would be
  seen on approach. Low obstacles at distance are the weak spot, with the
  `ABORTED` foot-contact path as the only backstop.

### First hardware session should be, in order

1. Robot on a stand, off the ground. Toggle avoidance on, watch the overlay, and
   tune `ROI_*` and `NEAR_THRESH` against real obstacles at real distances.
2. Check the reported inference time on the dashboard; confirm the control loop
   is not visibly stuttering.
3. Only then, on the ground, in manual mode, walk it at a single obstacle.
4. GPS/autonomous mode last.

---

## PLANNED — migrate ground-contact sensing from FSR to current sensing

Decided direction, not yet implemented. Ground contact (used only for the abort
check — a foot touching down early, mid-swing, triggers `handle_recovery`) currently
comes from four digital FSR pins in `Pico/fsr.py`, one per leg, read as a plain
GPIO high/low through a physical pull-down resistor: `fsrs = [FSR(16), FSR(17),
FSR(18), FSR(19))]`, and `any_touchdown = any(f.state for f in fsrs)` in
`pico_main.py`. The plan is to replace this with current sensing on the joint
motors instead — detecting a stall/current spike (the leg meeting unexpected
resistance) rather than a dedicated foot-mounted pressure sensor.

**Not designed yet — flagging what the migration actually has to answer, not
guessing at it:**
- *Where the current gets measured.* **Per-joint, off the BTS7960's own `IS` pins**
  — see the callout at the top of this file. The sense element is already in the
  driver chip (a ~1/8500 current mirror), so this needs a sense resistor and an ADC
  pin per joint, not a new shunt. It is also not 12 readings gathered centrally:
  each Pico only reads its *own* three joints, and `GP26`/`GP27`/`GP28` (ADC0/1/2)
  are free on every board for exactly that. The existing `INA219` in
  `power_monitor.py` reads total *pack* current only — one number for the whole
  robot, not per-leg, so it cannot answer "which foot touched down" on its own.
- *Stall vs. touchdown are not the same event.* A current spike means the leg met
  resistance — that's also true for hitting an obstacle mid-swing, binding at a
  joint limit, or simple stiction, not only "foot reached the ground." The FSR is
  specific to ground contact; current sensing is a broader "something stopped this
  joint" signal and will need its own logic to distinguish the cases (or the
  abort logic needs to become "the leg stalled," a real semantic change, not just a
  sensor swap).
- *Threshold tuning is different, not simpler.* FSR threshold is a fixed digital
  high/low against a known resistor. A current threshold has to sit above normal
  swing-phase motor current (which itself varies with `kp`/duty cycle, bench-tuning
  which is already an open item above) and below a stall — those two need to be far
  enough apart under real load to have a safe midpoint.

**Keep this in mind for other work, not just this entry:** any future change
touching `fsr.py`, the abort/`ABORTED` protocol, or `handle_recovery` should treat
FSR as the *current, temporary* mechanism, not a permanent architecture decision —
don't build more FSR-specific tooling or tuning on top of it without checking
whether this migration has since landed.

---

## Homing — a manual step you have to do, before every power-on

Every Pico's encoder starts counting from wherever the leg physically is when it
boots — the firmware has no way to know the real angle on its own. It currently
assumes `initial_angle=0`, but the IK's neutral standing pose is
**roll −15.55°, pitch 44.4°, knee 85.1°**, not zero. So the first gait frame used to
command ~45° and ~95° of travel from a wrong assumed position, at effectively full
PWM. **Resolved below — the whole flow (Home → Stand → Go → Stop) is built and
verified; one open question about mechanical confirmation remains at the end.**

**Manual, mechanical, not automated: before powering on, position each leg by hand**
into this reference pose, one leg at a time, and treat that as the zero point:

- **Hip roll = 90°** — abductor perpendicular to the body, pointing up.
- **Knee = 180°** — locked straight, thigh and shin colinear.
- **Hip pitch = 0°** — the leg (thigh+shin, straight) perpendicular to the body's
  lengthwise axis, no fore/aft lean.

This isn't a guess — it's derived from that description using the actual IK/FK code:
with the knee locked straight the thigh-shin triangle degenerates, which forces the
knee-side interior angle to exactly 0° regardless of segment length, which in turn
forces pitch = 0° to be the *exact* angle with zero fore/aft foot offset (verified:
`calculate_fk(90, 0, 180)` gives y = 0.0000 cm, and round-trips back through
`calculate()` to the same three angles). See `HOME_POSE` in `ik_and_gait.py`.

All four legs get commanded the identical standardized angles here — it's each
joint's `reverse` flag on the Pico that makes the same command swing each leg out to
its own correct physical side.

### RESOLVED — Home button, one leg at a time
How does the firmware know a leg has been placed and is ready to be zeroed? It
doesn't, on its own — the human says so, one leg at a time, from the web dashboard.
Each Pico recognizes a 2-byte `HOME_MARKER` (`0xAB 0xAB`, distinct from the gait
protocol's `0xAA 0xAA` start marker) that means "wherever I physically am right now
IS HOME_POSE" — it calls `zero_at()` on all three joints (new on `JointController`,
same formula as the `initial_angle` setup in `__init__`, just callable after boot),
then acks `HOMED,<id>\n`. **Nothing moves when this runs** — it only redefines what
the encoder count means.

The dashboard has a `Home FL` / `Home FR` / `Home RR` / `Home RL` button, one per
leg, exactly as planned ("each leg gets homed independently 1 by 1"). `pi5_main.py`
tracks `self.homed[leg_id]`, sourced only from the Pico's ack (not just "we sent the
command"), and `request_stand()` / `engage_walking()` both hard-refuse — server-side,
not just a greyed-out button — unless every leg reports homed.

### RESOLVED — boot no longer moves the legs
It used to ramp straight into the walking gait as soon as it powered up, which —
combined with the fact that nothing verified homing had actually happened — meant an
unhomed robot would still slam its legs to wherever the gait's first frame put them.
Boot now only runs leg identification and prints a reminder; every Pico just holds
its power-on position (target 0,0,0) under light PID, which is what produces the
small holding jiggle rather than a real move. Motion only starts once the operator,
in order: homes all four legs, presses **Stand**, then **Go** (both below).

### RESOLVED — smooth ramps instead of one big jump: Stand and Go
Even with homing done correctly, going straight from HOME_POSE into the walking
gait's first step is itself a big move (**105° of roll, 44° of pitch, 95° of knee**
— see the table below). `ik_and_gait.cartesian_ramp()` interpolates a move like that
in a straight line in foot-position space over 40 steps; `pi5_main.build_ramp()`
wraps it for any fixed start pose → per-leg target. Verified: a ramp starts exactly
at its start pose, ends at its target, and the intermediate foot path is a straight
line to within 0.02 cm (rounding).

That one big jump is now split into two smaller, explicitly user-triggered moves
instead of a single automatic one at boot:

- **Stand** (`request_stand()`) ramps every leg from HOME_POSE into a static,
  feet-under-hips pose (`self.stand_pose`) — refuses unless every leg is homed.
- **Go** (`engage_walking()`) ramps from `self.stand_pose` into the walking gait's
  first frame, then starts the continuous cyclic walk — refuses unless the robot is
  already standing.

| joint | HOME_POSE | gait neutral stance | travel |
|---|---|---|---|
| roll  | 90.0°  | −15.55° | −105.5° |
| pitch | 0.0° | 44.44°  | +44.4°  |
| knee  | 180.0° | 85.11°  | −94.9°  |

(Table is the original single HOME_POSE → gait-neutral jump that motivated building
a ramp at all — the numbers above show why slamming straight there was the problem
in the first place. Stand and Go now cover that distance in two separately-gated
hops rather than one.)

Sending a one-shot ramp to all four legs at once (rather than one leg's recovery
path) needed a small worker change: the normal cyclic-gait path always phase-offsets
each leg's buffer index and always ends with the *cycle* marker. A one-shot,
multi-leg send needs neither — the four ramps are independent point-to-point paths,
not a shared cycle sampled at different phases, so applying the phase rotation would
have each leg read a different, wrong ramp entry (verified this directly: with the
real offsets applied, a nonzero-offset leg samples the wrong entry; with offsets
zeroed, every leg samples its own ramp correctly). `send_entire_gait()` takes a
`cycle` flag, and the worker picks offsets `[0,0,0,0]` and the one-shot marker when
`cycle=False`.

### RESOLVED — Stop
Every Pico recognizes a third 2-byte command, `RELAX_MARKER` (`0xAC 0xAC`), that cuts
PWM to zero on all three joints without touching `gait_buffer`, `current_targets`, or
the encoder ISR. Pressing **STOP** on the dashboard sends this to every identified
leg, and also clears `walking_enabled`/`standing` on the Pi so the cyclic gait stops
being re-sent. Power resumes automatically — no separate "resume" command — the
moment either a `HOME` command or a complete gait/ramp frame arrives, which is what
pressing **Home** or **Stand** again naturally does.

**Read this before using it:** Stop does not lower the robot into any kind of
resting pose first. If the robot is standing or walking under its own weight when
you press it, cutting power will let the legs sag or the robot collapse the instant
torque drops — there is no sit-down sequence. It's built for "the robot is already
off the ground or otherwise supported and I want to relax the motors without losing
homing," not as a safe way to halt a walking robot mid-stride.

### Bug caught while building Stand/Go, not previously exercised
`cartesian_ramp()` unpacked its target with `calculate_fk(*target_angles)`. A
gait-frame entry is `[roll, pitch, knee, is_swing]` — 4 elements — so this raised
`TypeError` the moment it ran against a real gait frame instead of the 3-element
tuples the one existing test used. It would have crashed the first `engage_walking()`
call (and, before that, the original boot-time ramp) the first time it actually ran,
on hardware, with `rclpy` installed. Fixed by slicing to `[:3]` before unpacking.

### Still open, and worth deciding before any of this is trusted
Homing has no mechanical confirmation at all — if a leg is 10° off from the real
pose when you press its button, the firmware has no way to notice. It's a straight
trust-the-human step, just now a button press instead of "power on and hope." A hard
stop or limit switch would close this gap; not built here since it needs a decision
about the mechanism.

---

## Before you walk it

### Set LEG_ID on each Pico
`pico_main.py` has a `LEG_ID` constant at the top. Each of the four boards needs a
**different** value matching the corner it is bolted to:

| `LEG_ID` | Corner |
|---|---|
| `0` | Front Left |
| `1` | Front Right |
| `2` | Rear Right |
| `3` | Rear Left |

Each board announces `LEG,<id>` over UART every 500ms until it receives its first
gait frame, and the Pi builds the port→corner map from that — so UART wiring order
no longer matters. But two boards sharing an ID, or one set to the wrong corner,
produces a wrong gait phase and the robot falls. **The Pi logs the map it detects at
startup; check it before any powered walking.**

Confirmed on re-review that a *duplicate* ID fails safe rather than dangerously:
the second board to claim an ID is logged as an error and never enters
`port_by_leg`, so `request_home_leg` refuses it, `all(self.homed.values())` never
becomes true, and STAND is refused. You get a robot that will not stand, not one
that walks on three legs. A *wrong but unique* ID does not fail safe — all four
home, and the gait phases go to the wrong corners. Check the logged map.

### Set the left/right `reverse` flags — now matters for turning, verify it
The joint setup in `pico_main.py` takes a `reverse` argument per joint, currently
`False` everywhere. Left and right legs are mirror-image copies — the abductor
segment sticks outboard on both sides — and a reflection reverses handedness, so
one side needs its motor polarity flipped. Manual per-board setting, like `LEG_ID`.

**"The commanded angles are identical either way" is only true while walking
straight.** Verified: `build_gait` commands FL ≡ FR and RL ≡ RR joint-for-joint
at `yaw_deg == 0`, so `reverse` does the entire left/right mirror. But a **turn**
commands left ≠ right — a body spin rotates every foot the *same* angular
direction about the centre, which is a rotation between the two sides, not a
reflection, so `reverse` alone cannot produce it. `body_twist_xy_path` converts
the arc into each leg's own local frame with `LEG_SIGN_X`, and `reverse` then
maps that to physical motion. The turn *kinematics* are verified in
`quadruped_sim --report` (body spins the correct direction, margin/rate hold),
but the sim does not model `reverse`, so **whether the `reverse` flags compose
correctly with a turn is a bench check** — do it on a stand, off the ground,
before any powered turning.

### Verify the IMU roll/pitch signs — do this one first
On a stand, legs off the ground, watch the `[IMU Reflex] Levelling. Roll ...
pitch ...` line: tipping the chassis **right side down** must print a **positive
roll**, and **nose up** must print a **positive pitch**. If either is backwards,
flip that term's sign in `ik_and_gait.attitude_height_offsets()`.

Get this wrong and the levelling is positive feedback — it grows the tilt instead
of cancelling it, up to 8.6° of self-inflicted lean against a 2.4 cm stability
margin. Full write-up and the numbers: *Will make the robot fall over → OPEN — the
IMU roll/pitch signs are unverified*.

### Front/rear mirroring is handled in software — verified
The IK solves a **knee-forward** leg: at neutral stance the knee node sits at
local y = +18.8 cm. That matches the **rear** pair. The **front** pair is bolted
on turned round so its knees point back (toward the rear knees, as on a real
dog), so the front legs' stride is mirrored in software: `LEG_SIGN_Y = -1` for
the front pair, applied inside `body_twist_xy_path` (this replaced the old
`mirror_y=(leg_id in FRONT_LEGS)` flag; the two are equivalent and
`body_twist_xy_path` at `yaw == 0` reproduces the old gait term for term).

Verified numerically: during stance the front feet travel one way in their
*local* frame and the rear feet the opposite way, but `LEG_SIGN_Y` makes all
four move **backward in the body frame** together — which is what drives the
body forward. Without the flip the front legs would push against the rear.

It is a spatial mirror, **not** a time reversal. Reversing the cycle would also
shift each flipped leg half a cycle and scramble the FL → RR → FR → RL crawl
order.

**One thing `LEG_SIGN_Y` does NOT do, and must not be confused with:** it mirrors
the *stride direction*, not the *knee bend direction*. Whether a given knee angle
bends the joint fore or aft is a property of the assembly and the `reverse` flag
on that joint's `JointController`, not of the gait. So "the front knees face the
rear knees" is handled in two separate places — stride by `LEG_SIGN_Y` (verified
above, in software), bend direction by the per-joint `reverse` flags (still all
`False`, still a bench check — see the entry above this one). Getting
`LEG_SIGN_Y` right does not tell you the `reverse` flags are right.

A stale docstring on `GaitPath.update_params` used to say `mirror_y` applied to
"the rear pair, whose knees point forward", contradicting `FRONT_LEGS` three
screens above it. The code was always right (front pair mirrored); the comment
has been corrected.

### Body geometry (set — recorded here because it lives nowhere else)
`quadruped_sim.py` uses `BODY_LENGTH = 67.5`, `BODY_WIDTH = 53.0` cm. Both are
**hip-pivot spacings**, which is what the support polygon is built from — the shell
is 950mm end to end, but the hip pitch axes are only 675mm apart. Using the outer
length here would flatter the stability margin.

Same file has `LEG_FLIP_X` / `LEG_FLIP_Y`, modelling left-right mirroring and the
front pair's reversed mounting. `mirror_y` is derived from `LEG_FLIP_Y`, so the
mount model and the gait cannot silently disagree — but if your mechanical layout
differs from what those tables say, fix them or the sim will lie to you.

---

## Debug tool: per-leg deactivation

The dashboard has a `Deactivate <leg>` / `Reactivate <leg>` toggle per leg, for
bench testing. Deactivating a leg does **not** change the gait loop in any way —
`pi5_main.py` still computes that leg's target every tick exactly as if nothing
were deactivated — it only skips the wire write (open marker, per-step payload, and
close marker, all three) for that leg's Pico. That Pico is left completely alone:
no empty frame, no reset, it just keeps holding whatever it was last actually told.
The other three keep walking normally.

Does not touch `self.homed` — deactivating and reactivating a leg never requires
re-homing it. Intended for isolating one leg's Pico on the bench (or watching the
other three walk without one leg's motion muddying the picture), not for anything
load-bearing: a deactivated leg gets no updated commands at all, so if it was mid-air
when deactivated, it stays exactly there.

---

## Will make the robot fall over

### OPEN — the IMU roll/pitch signs are unverified, and a wrong one is positive feedback

**The only open item in this section, and the most dangerous unverified thing in
the codebase.** Nothing in the code or the simulator can detect it; it needs two
minutes on a stand.

`attitude_height_offsets()` levels the body by making the legs on the low side
longer and the legs on the high side shorter. To know which side is low it trusts
a convention: **positive roll = right side down, positive pitch = nose up.** The
maths is correct *for that convention* — `dz = gain * (hx*tan(r) - hy*tan(p))`
extends the right legs when `r > 0` (`hx` is +26.5 cm there) and shortens the
front legs when `p > 0` (`hy` is +33.75 cm), both restoring.

But roll and pitch come out of `IMU._quat_to_pitch_roll()` in the **BNO085's own
body frame**, and which physical direction that frame's axes point depends
entirely on how the breakout is bolted into the chassis. Rotate the board 180°
about its vertical axis and both signs flip. Mount it on its side and they swap.
The quaternion maths is standard and correct — the question is not "is the
conversion right", it is "does the board's +X actually point forward".

If either axis is inverted the correction runs the wrong way, which is **positive
feedback**: a small tilt produces a correction that increases the tilt, which
produces a bigger correction, until it saturates at `ATTITUDE_LIMIT_CM = 4.0`.

| | |
|---|---|
| Limit | 4.0 cm of differential leg height |
| Track width | 53.0 cm (`BODY_WIDTH_CM`) |
| Induced roll at the limit | `atan(8/53)` ≈ **8.6°** |
| Worst-case stance margin | +2.38 cm (`quadruped_sim --report`) |

8.6° of self-inflicted lean, added to whatever tilt started it, against a support
triangle with 2.4 cm of margin. The robot puts itself over, and it does it faster
the harder it tries to correct.

Why it has not bitten yet: `ATTITUDE_GAIN = 0.6` and the 12-sample IMU average
make the runaway take a second or two rather than being instant, and the robot has
never walked unsupported. It is also completely invisible in simulation —
`quadruped_sim` feeds `attitude_height_offsets` a *commanded* tilt, so the sign
convention is true by construction there and the sim will report a clean margin no
matter which way the real board is mounted.

**Bench check — on a stand, legs off the ground, before the robot ever carries its
own weight while walking:**

1. Bring the Pi up and watch the `[IMU Reflex] Levelling. Roll ... pitch ...` line.
2. Tip the chassis **right side down**. `Roll` must print **positive**.
3. Tip it **nose up**. `pitch` must print **positive**.
4. If either is backwards, flip that term's sign inside
   `ik_and_gait.attitude_height_offsets()` — the docstring says to fix it there
   and not anywhere downstream, so that `pi5_main` and `quadruped_sim` keep
   agreeing. Re-run `quadruped_sim.py --report` afterwards.

The same "we assume it, we have never measured it" gap applies to the compass axis
signs (see *Compass* below) and to the per-joint `reverse` flags during a turn (see
*Before you walk it*). This one is the worst of the three because its failure mode
is divergent rather than merely wrong.

### RESOLVED — body shift, phased with the lift sequence
The sim reported 100% "statically stable" but that was a binary in/out test hiding
the real number: the **margin** — distance from the body centre to the nearest edge
of the support triangle — had a worst case of **+0.42 cm** at 67.5 × 53 cm. The cause
is geometric: with feet directly under the hips, lifting one leg leaves a triangle
whose hypotenuse runs corner-to-corner *through* the body centre, on the edge by
construction. 4 mm gets consumed instantly by payload offset, the swinging leg's own
mass, or any ground unevenness.

`ik_and_gait.py` now has `body_shift_profile()`: it leans the body 2 cm toward the
diagonally-opposite hip from whichever leg is about to lift, one tick ahead of the
lift (during the four-feet-down beat), then leans back. `apply_body_shift()` folds
that into each leg's foot path in its own local frame. `pi5_main.build_gait()` calls
both; `quadruped_sim.py` calls the identical functions, so the two cannot disagree.

The first attempt used a box filter to smooth the profile and only reached +0.81 cm
— worse than expected. The filter was straddling the sign flip at each lift boundary,
which is also the instant the margin is thinnest, diluting the lean exactly when it
mattered. **No smoothing (`smooth_width=1`) is now the default**, verified against the
alternative — see the comment on `body_shift_profile` for the measured numbers.

Result: **worst-case margin is now +2.38 cm**, clearing the 2 cm bar, at a joint-rate
cost of 235 → 266 deg/s (65% → 74% of the motor's free speed — still 26% headroom).
`quadruped_sim.py --report` now shows `VERDICT: gait is viable`.

### RESOLVED — `height2` (stance push) set to 0
Three feet are planted at different points in the stance phase, so a nonzero
`height2` commanded them to depths spanning 2.17 cm — on flat rigid ground they
cannot all be there, and it becomes body bob or lost contact. `STANCE_PUSH` is now
`0.0` in `pi5_main.py`, `quadruped_sim.py`, and `single_leg_test.py`. Downward reach
for uneven terrain would need closed-loop FSR contact to do properly, not a fixed
per-step push — left for later, deliberately not brought back as a blind default.

### RESOLVED — `STEP_TICK_MS` raised 20 → 40 ms
Kept here because the tradeoff is worth understanding before anyone lowers it again.
40 ms gives a peak of 235 deg/s (65% of free speed) at 16.7 cm/s. The simulator now
checks this every run and fails if the commanded rate exceeds the motor.

Peak commanded joint rate, per phase, at the old 20 ms tick:

| phase | roll | pitch | knee |
|---|---|---|---|
| stance | 11 dps | 91 dps | 69 dps |
| **liftoff** | 71 dps | 253 dps | **469 dps** |
| swing | 51 dps | 345 dps | 299 dps |
| **touchdown** | 71 dps | 163 dps | **469 dps** |

The goBILDA 5302 at 99.5:1 / 60 RPM gives **360 deg/s at the output shaft, free
running**. The gait asks for **1.30x that** at liftoff and touchdown, and under the
load of a real quadruped nothing like 60 RPM is available. The PID will simply
saturate and the leg will lag its target — the foot lands late and in the wrong place.

The peaks are at the phase boundaries, not mid-swing: the foot reverses direction
there, and with only 4 swing samples that corner is sharp.

| `STEP_TICK_MS` | cycle | speed | peak rate | |
|---|---|---|---|---|
| 20 (current) | 0.40 s | 33.3 cm/s | 469 dps | too fast |
| 25 | 0.50 s | 26.7 cm/s | 375 dps | too fast |
| 30 | 0.60 s | 22.2 cm/s | 313 dps | 87% of free speed — still tight |
| **40** | 0.80 s | 16.7 cm/s | 235 dps | 65% — realistic under load |
| 50 | 1.00 s | 13.3 cm/s | 188 dps | conservative |

Not changed, because the right value depends on what the motors actually deliver
under load, which is a bench measurement rather than something derivable. **Start at
40 ms** and work down while watching whether the legs track their targets.

Softening the corner would also help — more swing samples, or easing the velocity
into liftoff/touchdown rather than starting the arc at full horizontal speed.

Note the same argument in Y is already handled — stance `y` is deliberately linear in
time so all planted feet travel at identical speed. An elliptical stance would make
them differ by up to 0.85 cm/tick (127% of a step) and scrub against the ground.

---

## Will misbehave

### RESOLVED — `current_state` conflated operating mode with transient activity

`RobotState` was one field used for two unrelated things: MANUAL/AUTONOMOUS
(what the operator asked for) and RECOVERY (what the robot is doing right now).
Three bugs followed, the middle one able to drop the robot:

1. After any recovery the worker hard-set `current_state = MANUAL`, so a stumble
   silently dropped the robot out of GPS nav while the dashboard still read
   NAV: ON.
2. `nav_mode_callback` overwrote `current_state` unconditionally from a ROS
   executor thread. A NAV toggle landing between `handle_recovery()` staging a
   recovery and `_gait_serial_worker` reading it flipped the worker's
   `== RECOVERY` test false — **the recovery was never transmitted, and the
   aborted leg stayed frozen at zero PWM with `has_aborted` latched while the
   other three kept walking.** That is a fall.
3. The worker's state check raced that same callback.

**Fixed** by splitting into two fields with one writer each:
`current_mode` (`RobotMode.MANUAL` / `AUTONOMOUS`) written only by
`nav_mode_callback`, and `current_activity` (`RobotActivity.NORMAL` /
`RECOVERY`) written only by the recovery path. The worker gates on
`current_activity`, which the nav toggle cannot touch, so (2) is structurally
impossible now; clearing a recovery no longer resets the mode, so (1) is gone;
and there is no longer a single field two threads fight over, so (3) is gone.
`RobotState` remains as a back-compat alias of `RobotMode` — `.RECOVERY` was
deliberately removed from it so a stale reference raises instead of silently
comparing a mode against an activity. Verified against the source: no
`current_state` in executable code, nav callback touches only `current_mode`,
recovery touches only `current_activity`.

### RESOLVED — one leg recovers while the other three keep walking: policy is "go to neutral"
`handle_recovery` used to send the recovery path only to `trigger_serial`, leaving
the other three legs cycling their existing walking buffer — trying to keep walking
on three legs while the fourth recovers. Policy decided: **go to neutral**, not
freeze in place. The other three are now sent, in the same recovery pass, a direct
one-shot move to `self.stand_pose` (the same static point the aborting leg's own
`get_recovery_gait` already targets) — so all four legs converge on the same
feet-under-hips pose. `standing`/`walking_enabled` are cleared when recovery starts
and `standing` is set once it completes, so **Go** is required to resume walking
rather than the robot silently continuing on whatever it was doing.

**Caveat, not fully solved:** the other three legs have no live position feedback —
the Pi only learns a leg's actual angle when *that* leg is the one that aborts and
reports it. So unlike the Home→Stand→Go ramps, this can't be a smooth Cartesian
interpolation from a known start; it's a direct PID move to `stand_pose`, bounded by
the same PWM limits as any ordinary gait step. Walking-gait poses stay close to
`stand_pose` by construction (that's the whole point of the stand height), so the
jump should be small, but it hasn't been measured on hardware.

### RESOLVED — steering is now a body twist (yaw), not differential stride

Was: `chosen_direction` mapped to a left/right stride-length difference, which
turned the robot like a skid-steer — every foot moving straight fore/aft, the
two sides covering different ground, the feet scrubbing sideways as the body
yawed. The hip-roll joint did almost nothing during a turn. `GaitPath`'s
`direction_angle` — nominally the omnidirectional mechanism — was hardcoded to
`0` everywhere and, tested, only strafed the body (translated it diagonally)
without ever yawing it.

Now: `ik_and_gait.body_twist_xy_path()` takes a forward stride **and** a yaw per
cycle. Each planted foot arcs about the body centre — its neutral (hip) position
rotated `± yaw/2` across the stroke — so the four feet phased together drive the
body through a real rotation, with the hip-roll joint carrying the lateral part
of each arc (this is how CHAMP / MIT-Cheetah-lineage controllers turn).
`pi5_main`'s loop maps `chosen_direction` (+ = turn right) to a yaw rate plus a
forward stride that tapers to zero by `YAW_FULL_SPIN_DEG` (90°), so a hard
LEFT/RIGHT spins in place and a moderate heading error arcs while still
advancing.

Verified in `quadruped_sim.py --report` across the full command range:
`yaw_deg == 0` reproduces the old straight gait **term for term** (margin
+2.38 cm, 266 deg/s, 55.8 cm/4 cyc — unchanged); every turn keeps one leg
airborne, the FL→RR→FR→RL crawl order, joint rate ≤ 283 deg/s (79%), and all
foot targets reachable. Full spin is ~13 deg/cycle → ~16 deg/s → a 90° turn in
~5.5 s.

**Still open / notes:**
- *There is still no zero-velocity "keep standing, hold heading" travel state.*
  `chosen_direction = 0` means walk forward. STOP de-powers; a large obstacle,
  or a completed mission, makes the loop march in place (stride 0) — feet lift,
  body holds, no ground covered. That covers mission end (now RESOLVED, below),
  but it is not a true "stand still and hold this heading" state.
- *A "spin in place" drifts.* The phased crawl means only 3 feet are planted at
  any instant, so each single-leg lift during a spin leaves a few mm of
  un-cancelled translation — measured 3–8 cm of drift over a 53° spin, and
  slightly asymmetric left vs right (the front-leg mirror). Nav recomputes the
  bearing from GPS every cycle so it self-corrects; a true zero-drift spin would
  need the arc centred on the support-triangle centroid, not the body centre.
- *`direction_angle` in `GaitPath` is now dead* for production (still used by
  `gait_testing3.py`). Left in place; `build_gait` no longer calls `GaitPath`
  for the gait itself, only `swing_steps()` uses it (for the lift schedule).
- The `TURN_BODY_SHIFT_CM` ramp (2 → 4 cm of tripod lean as the turn tightens)
  is what keeps the margin up during a turn — see its comment. Straight walking
  is untouched.
- `chosen_direction` still means "travel direction" in MANUAL and "heading
  error" in AUTONOMOUS — one variable, two meanings. Harmless with the yaw
  mapping (both want "yaw toward this"), but the `current_state` conflation
  above is the related cleanup.

### RESOLVED — mission end now holds position; route is editable from the dashboard

`Navigator.calculate_nav` returns `None` once the waypoints are exhausted. The
control loop used to let `chosen_direction` fall through to the last manual
value, so the robot walked off forever. It now sets `chosen_direction = 0` and
`stride_scale = 0.0` on that `None` — the march-in-place command from the
avoidance work — so the robot picks its feet up on the spot, stays standing and
IMU-levelled, and waits for STAND or STOP. The avoidance planner's stride is
folded in with `min()` now, not assignment, so a CLEAR decision (1.0) can no
longer undo that hold.

This also depended on there being a route at all. There wasn't a way to enter
one — `MISSION_WAYPOINTS` was two hardcoded pairs in `main()`. Now:

- `Navigator` takes an optional list, defaults to empty, and is fully
  lock-guarded (`set_waypoints` / `get_waypoints` / `progress` /
  `mission_complete`) because the control loop reads it at ~100 Hz while a ROS
  executor thread may be rewriting it. `set_waypoints` validates lat/lon range
  and always restarts the route at index 0.
- New topic `/apex/navigation/waypoints` (`Float32MultiArray`, flat
  `[lat, lon, ...]`, empty = "no route"). `waypoints_callback` on the
  controller hands it to `Navigator`.
- New topic `/apex/navigation/nav_cmd` (`Int32`: 1 START, 2 PAUSE, 3 STOP).
  START sets `AUTONOMOUS` + `reset_progress()` + clears pause; PAUSE sets
  `nav_paused` (the loop then marches in place without advancing the route);
  STOP returns to `MANUAL` + rewinds. `nav_paused` is a separate field, touched
  only by `nav_cmd_callback` and the loop.
- `stream_server` gains `/waypoints`, `/set_waypoints` and `/nav_control`
  (POST `action=start|pause|stop`). The status array grew four appended fields
  — `wp_index`, `wp_total` (`len >= 17`) then `nav_mode`, `nav_paused`
  (`len >= 19`) — so an older dashboard still parses.
- The dashboard's old standalone **Route** and **Obstacle Avoidance** cards are
  now one **Navigation** card with two collapsible sections (both start closed):
  *GPS Waypoints & Routing* (the NAV MODE master toggle, the point editor, and a
  **Start / Pause / Stop** transport row that greys out per state) and
  *Obstacle Avoidance* (the avoidance toggle + state readout, unchanged). The
  route status line reads e.g. "PAUSED — driving to waypoint 2 of 3".

NAV MODE and Start are now refused outright until a route is loaded, rather than
flipping AUTONOMOUS on to march in place. Three layers: the dashboard greys the
toggle out (`wp_total === 0`), `stream_server.toggle_nav` / `nav_control` return
409 without publishing, and `nav_mode_callback` / `nav_cmd_callback` in the
controller bail on `_route_loaded()` — so a message that bypasses the UI (replayed
topic, direct publish) still can't put the robot in nav mode with nowhere to go.
Verified end to end without hardware (`Navigator` editing, arrival advance,
concurrent-access smoke, `stream_server` route + `nav_control` publish, the
no-route refusals at every layer, 19-field status parse, and the preview server
driving a route through start → pause → stop).

Note the drift caveat from the steering entry above still applies to any turn,
and there is still no separate "hold heading while stationary" state — but
mission end is no longer one of the things that needs it.

### RESOLVED — blocking sensor reads moved off the control loop
The `while rclpy.ok()` loop in `pi5_main.main()` used to call `imu.update()`,
`compass.get_heading()` and (once a second) the INA219 reads **inline, every
iteration**. Those are synchronous I2C transactions — a few ms on a healthy bus,
but on a NAKing or wedged bus the kernel blocks for its I2C timeout, and while it
blocked so did steering resends, the IMU reflex and the avoidance stride command.

`sensor_hub.SensorHub` now runs one poller thread per sensor (IMU 50 Hz, GPS +
compass 10 Hz, INA219 1 Hz); each thread owns its hardware object exclusively and
publishes into a lock-protected snapshot. The loop reads `imu_snapshot()` /
`nav_snapshot()` / `power_snapshot()` — dict copies, never hardware — each with a
staleness cutoff, so a dead or hung sensor degrades to the safe default (flat
attitude, hold last heading, skip the battery check) instead of stalling the
gait. Two failure signals: snapshot freshness (poll ran, reading was bad/old) and
`thread_alive()` (poller blocked inside a hardware call right now); the loop logs
which poller is stalled every ~5 s via `SensorHub.health()`.

`GPSReader.update()` was already non-blocking (drains the UART buffer only) — it
rides the nav poller just to keep all sensor I/O in one place.
`CompassReader.get_heading()` now returns `None` (not `0.0`) on an I2C failure so
a wedged bus is distinguishable from a genuine due-north reading; the hub holds
the last good heading across a `None`. Self-test: `python sensor_hub.py` →
`SENSOR HUB OK` (covers a failing sensor and a hung poller).

Still inline and still blocking, but sub-millisecond so not worth threading:
`controller.read_pico_lines()` (non-blocking by construction, same buffered-drain
pattern as GPS) and `audio_engine.play()` (already fire-and-forget — it spawns
its own daemon thread, `play()` itself just does an `os.path.exists` and a thread
start).

### RESOLVED — IMU stabilization is now differential, not a common offset
It used to feed pitch into `center_stride_y` and roll into `lateral_roll_offset`,
applying **the same offset to all four legs**. Measured directly: at the maximum
correction values, the change in every foot's Z was **0.0000 cm** — a body
*translation* with zero restoring moment, so no gain would ever have made it work.

`ik_and_gait.attitude_height_offsets(roll_deg, pitch_deg)` now computes a **per-leg**
height change from each hip's position: `dz = gain * (hx*tan(roll) - hy*tan(pitch))`.
Raising the low corners and lowering the high ones is what produces an actual
restoring moment. `build_gait()` feeds this into `center_height_z` per leg. Verified
in the simulator: 15° of simulated roll now produces a measurable left/right foot
height difference; 15° of pitch produces a front/rear difference; zero tilt gives
identical heights across all four legs (as it must).

`gain = 0.6` (damped, not a full correction in one update — avoids overshoot) and
`limit_cm = 4.0` (caps how far one corner can be driven from stand height) are in
`pi5_main.py`; both are guesses that need bench tuning against the real BNO085.
`max_tilt_deg = 30` in the function itself clamps the input before it reaches
`tan()`, which blows up near 90°.

Sign convention: positive roll is taken as right-side-down, positive pitch as
nose-up. **If the BNO085 is mounted with either axis flipped relative to that, the
correction will actively tip the robot the wrong way — check this on the bench
before trusting it, ideally with the robot held up off the ground first.**

### Low-voltage alarm threshold may be unreachable — check which rail the INA219 is on

`pi5_main.LOW_VOLT_THRESHOLD = 4.75` V, compared against `INA219.get_voltage()`.
That is a sensible undervoltage trip for a **5 V regulated rail**, but the BOM
and README describe the INA219 as *battery* telemetry, and the electronics pack
is a **2S LiHV** — roughly 8.7 V full to 6.0 V empty. If it is wired across that
battery, 4.75 V is below fully-flat and `low_battery.wav` can never play; the
alarm is dead code. Decide which it is and set the threshold to match (~6.4 V
for a 2S pack, or leave 4.75 if it really is on the 5 V rail).

There is no longer a current side to this alarm — `MAX_CURRENT_MA` was removed
and the check is voltage-only, because it is unconfirmed whether a shunt is even
in the load path. See *INA219 — voltage-only for now* below for the full state.
Either way this is on the *electronics* supply — nothing monitors the 3S motor
pack, which is the one that actually gets hammered.

Verified correct while checking this, so it does not need re-deriving: config
word `0x399F` decodes to 32 V range / ±320 mV / 12-bit / continuous, calibration
2048 gives a 0.2 mA current LSB matching `raw * 0.2`, and the power LSB is 20×
that, matching `raw * 4.0` mW.

### RESOLVED — an out-of-range target left the motor at its last duty

`JointController.move_to()` returned early — before touching the PWM registers —
when `target_angle` was non-finite or outside ±360°. The guard itself is right
(it is what stops NaN surviving the clamp as full duty), but the bare `return`
meant the joint kept driving at whatever duty the previous call set. On a
saturated PID that is full duty into a stop, held until a good target arrives.

It also left `self.last_time` untouched, so the first good call after a run of
bad ones saw a `dt` inflated by the whole gap and dumped a large `error * dt`
straight into the integrator.

**Fixed:** the guard now zeroes both PWMs (coast), clears `integral` and
`prev_error` so nothing carries across the gap, and advances `last_time`. Still
low-likelihood — `pico_main` range-checks every payload before it reaches the
buffer — but it is now a safe failure rather than a latched one.

### Compass: declination + tilt now handled; hard/soft-iron calibration still not

Fixed:

- **Declination.** `CompassReader(declination_deg=...)` is fed
  `MAGNETIC_DECLINATION_DEG` (pi5_main, currently `-13.0` for northern NJ) and
  added to every reading, so `get_heading()` now returns *true* north to match
  the GPS bearings and Google-Maps coordinates. Edit the constant for your area.
- **Tilt compensation.** `get_heading(roll_deg, pitch_deg)` de-rotates the field
  into the horizontal plane (Honeywell AN3192 form) using the latest IMU
  attitude, which `SensorHub._nav_poll` now passes in. At roll = pitch = 0 it is
  byte-identical to the old `atan2(y, x)`, so there is no regression when level;
  it only removes the per-stride heading wobble when the body tilts.
- **Bad-sample rejection.** Returns `None` (not `0.0`, and not a garbage angle)
  on I2C `OSError`, on the QMC5883L overflow bit, and on an all-`0x0000` /
  all-`0xFFFF` block. Init does a soft reset first and records `configured`.
- **Frozen-heading detection.** `nav_snapshot()` exposes `heading_age` (time
  since the last *good* read — the shared nav poller keeps ticking on GPS alone,
  so `heading` staying non-None can't reveal a dead compass). Under AUTONOMOUS,
  `heading_age > HEADING_MAX_AGE_S` (3 s) makes the robot hold position instead
  of driving on a stale bearing, and drops the `compass` health bit live so the
  dashboard shows the amber "compass offline" banner.

Still open (descoped on purpose):

- **No hard/soft-iron calibration.** Raw `atan2` on a frame full of servo
  magnets and battery current carries a large *heading-dependent* offset that
  declination cannot remove. Needs a "spin 360° and collect min/max" routine
  writing a cal file. Until then, absolute heading accuracy is poor; the closed
  nav loop still converges because `calculate_nav` re-derives the bearing from
  the live GPS every pass and `ARRIVE_RADIUS_M` is 4 m.
- **Axis / sign not bench-verified.** The tilt-comp math assumes x-forward,
  y-right (or the pre-existing frame the old `atan2(y, x)` implied), z-down, with
  the BNO085 roll/pitch signs matching. If a bench heading check ever shows the
  robot turning *away* from a waypoint, the heading runs the wrong way and the
  `atan2` / roll / pitch signs in `CompassReader.get_heading` need flipping.
  (This is a no-op-at-level change, so it did not make anything worse.)

### RESOLVED — autonomous nav no longer drives on a dead sensor

Three related failures, all the same shape as the compass frozen-heading bug:

- **GPS goes silent → frozen fix.** `GPSReader` left `has_fix` / `lat` / `lon`
  latched at their last values when the receiver stopped sending, and the
  `AUTONOMOUS` gate only checked `has_fix` and the *poller* age (which the shared
  GPS+compass poller keeps fresh). Now `GPSReader.fix_t` timestamps the last
  positional GGA, `nav_snapshot()` exposes `fix_age`, and a fix older than
  `GPS_FIX_MAX_AGE_S` (5 s) counts as no fix.
- **No-fix `AUTONOMOUS` walked off blindly.** The "no usable GPS fix" branch
  printed a message but did **not** set `chosen_direction` / `stride_scale`, so
  they fell through carrying the last *manual* steering value at full stride —
  an autonomous robot that lost its fix drove forward in whatever direction the
  slider was last on. It now holds position, like the paused / mission-complete
  / heading-stale branches.
- **Dead sensors reported healthy.** `subsystem_health['gps']` / `['compass']`
  are updated live from the loop now (not just at boot), so a receiver or
  magnetometer that quits mid-run lights the dashboard degrade banner.

### RESOLVED — a camera that fails to open no longer reads as healthy

`USBWebcam.__init__` used to set `self.running = False` and return an object.
`_bring_up()` saw a successful construction, marked the camera up, and
`camera_loop` spun forever on `get_frame()` returning `None` while obstacle
avoidance silently starved. It now `raise`s, so `_bring_up` catches it, the
camera subsystem is marked down (degrade banner), and `camera_loop` returns
immediately — same as every other missing sensor.

### RESOLVED — `port_by_leg` mutated without the serial lock

`register_leg_announcement` inserts into `self.port_by_leg` from the control-loop
thread (a Pico that resets mid-run re-announces on every pass), while the gait
worker reads it via `active_legs()` on its own thread. An insert during the
worker's `sorted(port_by_leg.items())` is a "dict changed size during iteration".
Both sides are under `serial_lock` now, matching what `handle_recovery` and
`request_stop` already did.

### INA219 — voltage-only for now; confirm the wiring

**Needs a bench check on the actual board.** Two unknowns:

1. **What VIN− senses.** `LOW_VOLT_THRESHOLD = 4.75 V` in `pi5_main` suits the
   5 V regulated rail (warn when the buck sags). If VIN− is on the 2S pack
   instead (~6.0–8.4 V LiPo / 6.6–8.7 V LiHV) the alarm can never fire and the
   threshold should be ~6.2–6.6 V. There's a `TODO(hardware)` on the constant.
2. **Whether a shunt is in the load path** across VIN+/VIN−. If the board is
   wired as a plain voltmeter (VIN+/VIN− bridged), `get_current()` /
   `get_power()` are meaningless.

Current state: **only `get_voltage()` is used.** `sensor_hub._power_poll` no
longer calls `get_current()` (it stores `None`), and the `pi5_main` power check
is voltage-only. `INA219.get_current()` / `get_power()` are kept intact but
uncalled — once the shunt path is confirmed, re-enable the one line in
`_power_poll` and restore the current check in `pi5_main`. The config register
(`0x399F` + cal `2048`) assumes ±320 mV / 0.1 Ω = ±3.2 A FSR, so if the INA219
turns out to be on a motor rail that draws more, the current reading would pin
and the (unchecked) overflow bit would set — another reason to verify before
trusting it.

### RESOLVED — two repo files could not run at all

- **`single_leg_test.py` could not import on the Pi.** Line 19 was
  `from InverseKinematics.ik_and_gait import ...`, but the directory is
  `inverse_kinematics`. Linux is case-sensitive, so this was an immediate
  `ModuleNotFoundError` — and the README recommends this file as *the* way to
  test without ROS. Fixed. Still worth knowing it drives the legacy `GaitPath` /
  `direction_angle` steering, not `body_twist_xy_path`, so it is a joint-level
  bench tool and not a preview of how the robot actually walks.
- **`test_pi_quadruped.py` tested an API that no longer exists.** It asserted on
  `controller.current_state` and `RobotState.RECOVERY`, both removed when the
  state machine was split into `current_mode` / `current_activity`, so it failed
  at the first assertion. Updated to the split fields, and it now also asserts
  the thing the split was *for*: that recovery clears the activity and leaves the
  operating mode alone.

### RESOLVED — Pico PID state was not reset when drive is cut

`pico_main`'s `if has_aborted or not powered:` branch zeroes all six PWM
registers but leaves each `JointController`'s `integral`, `prev_error` and
`last_time` untouched. On resume, `dt` is the entire time drive was off.

Measured: after a 120 s Stop, the first `move_to()` put the integrator straight
to its clamp in a single call, because `error * dt` = 20 × 120. Bounded by the
clamp so nothing ran away, but it is the identical stale-`dt` failure mode the
out-of-range guard already fixes (RESOLVED, above).

**Fixed:** `JointController.reset_pid()` drops the integral and derivative state
and restarts the `dt` clock. `pico_main` tracks `drive_was_cut` and calls it once
on the transition back to driving, so it runs on the edge rather than every pass.
Verified: integral 0.040 after a 120 s gap, against 50.0 (the clamp) before.

### RESOLVED — `fsr.py` interrupt helpers could not both be used

`on_touchdown()` and `on_liftoff()` each called `self._pin.irq(...)`, and a Pin
holds only one handler — registering the second silently replaced the first.
Both also passed a `lambda`, which allocates, and MicroPython forbids allocation
inside a hard IRQ, so the handler could fail at the worst possible moment.

Replaced with a single `on_edge(callback, rising=, falling=)` that registers one
bound method (`_on_irq`, no allocation) and reports which edge fired via
`callback(is_touchdown)`. Still unused — `pico_main` polls `.state` — but it is
no longer a trap for whoever wires up interrupt-driven contact next.

### IK clamps unreachable targets silently
`InverseKinematics.calculate` clamps out-of-range law-of-cosines arguments and the
shoulder-to-foot distance instead of reporting that a target cannot be reached. Ask
for z = 55 cm and the foot lands at 52.11 with no exception and no flag, so the
caller cannot tell the difference between "done" and "as close as I could get".

Harmless for the current gait (it uses z = 31–38.5 cm, well inside the 2.47–51.21 cm
annulus) but it will hide mistakes in any future terrain or body-shift work. A
`reachable` flag on the result would fix it; not added because nothing reads it yet.

### RESOLVED — a blocked leg sat at 100% PWM indefinitely (needs a Pico reflash)

**This was the most dangerous thing in the firmware.** Measured by running the
real `JointController` against a frozen encoder (leg jammed at 10°, target 30°):

| t | integral | I term | forward duty |
|---|---|---|---|
| 0.05 s | 1.0 | 0.02 | **65535 (100%)** |
| 1.0 s | 20.1 | 0.40 | **65535 (100%)** |
| 5.0 s | 50.0 (clamp) | 1.00 | **65535 (100%)** |
| 10 s+ | 50.0 | 1.00 | **65535 (100%)** |

The windup itself is fine — that is not the problem (see the entry below). The
problem is `kp = 0.8`: at 20° of error the P term alone is **16.0** against an
output range of ±1.0, so the duty pins at full and *stays* there. Nothing ever
takes it down. There is no stall timeout, no current limit, no thermal cutout,
and no "error stopped changing" check anywhere in `move_to()` or `pico_main`.

A goBILDA 5302 at 99.5:1 stalls around 9 A. Held indefinitely, that cooks the
motor, the BTS7960, or the pack — whichever gives first.

**Fixed with a software stall guard**, no new hardware needed.
`JointController._update_stall()` watches for the output being saturated
(pre-clamp `|output| >= 1.0`) while `|error|` stays above the deadband and
refuses to fall by `STALL_PROGRESS_DEG` (2°). After `STALL_TIMEOUT_S` (1.5 s) it
latches `self.stalled`, zeroes both PWMs, and stays latched until `clear_stall()`
or `zero_at()`. `pico_main` polls the three joints and raises the existing
`ABORTED` path (plus a `STALL,<leg>,<joint>` line for the log), so the Pi runs
its normal recovery instead of leaving three legs walking. A new frame from the
Pi clears the latch, so a jam retries every 1.5 s rather than spinning at full duty.

**Progress, not duty, is the discriminator** — a legitimate large move also
saturates, it just closes its error.

**Progress is now two signals, either of which clears the window:** the error
fell by 2°, *or* the encoder moved by 2° worth of ticks. The encoder term was
added on re-review and is what makes a false latch structurally impossible rather
than merely unlikely. Without it, a joint that tracks a fast swing with a
permanent several-degree lag is saturated the whole time and its error never
falls 2° below the ratchet floor, so the 1.5 s timer would run out mid-stride and
abort a perfectly healthy leg into a three-legged recovery — itself a fall risk.
A jammed motor has a stationary encoder by definition, so requiring both costs
nothing on a real jam: it still latches at exactly 1.50 s. Re-verified with a
joint driven at 120°/s against a target running away at 200°/s — 720° of travel,
never latched.

Verified against a first-order motor model running the real controller
(`scratchpad/verify_stall.py`):

| case | result |
|---|---|
| jammed joint | latches at 1.50 s, both PWMs zeroed |
| 90° free move | completes, never latches |
| 10 s of walking gait | never latches |
| 2°/s creep toward target | never latches |
| jam cleared + `clear_stall()` | drives normally again |

The BTS7960 `IS` current sensing in the callout at the top is still worth doing —
it detects a jam in milliseconds rather than 1.5 s, and can tell a jam from a
joint that is merely loaded. This guard is the backstop, not the replacement.

### RESOLVED — FSR abort fired on the FIRST swing step of every leg

`pico_main.py` line ~200:

```python
any_touchdown = any(f.state for f in fsrs)     # fsrs = FSR(16..19), FOUR of them
...
if any_touchdown and current_step_swing:       # current_step_swing is THIS leg's
    → ABORTED
```

Each Pico drives **one** leg but reads **four** FSR pins, and `any()` collapses
them. The gait is a crawl: whenever one leg is swinging, the other **three are
planted by construction**. So `any_touchdown` is True for the entire duration of
every swing phase, and the condition reduces to "abort whenever this leg swings."

Leg L would have aborted on its first swing tick, every cycle, forever. It never
bit only because nothing is wired to GP16–19, so the pins read low.

**Fixed:** the board now reads one sensor — `foot = FSR(FSR_PIN)`, tested as
`own_touchdown` — which is what *"my own foot touched down while I should be
airborne"* actually means. `FSR_PIN` is a documented constant next to `LEG_ID`.

**Set `FSR_PIN` to match your wiring before connecting the sensors.** It
defaults to 16. If each board instead gets all four signals, set it to whichever
pin carries *this* leg's foot.

### PID: `kp` still needs bench tuning (windup ruled out, `kd` fixed)
Simulated against a motor model (360 deg/s free speed, first-order response,
stiction, and real encoder quantisation), running the actual `JointController` code:

- **No windup, and it is genuinely bounded.** In normal walking the I term peaks at
  0.2–2.2 against its clamp of 50 (0.4–4%): the deadband zeroes it whenever
  |error| < 1° and the error changes sign every cycle. Re-measured against a
  *stalled* leg, where the error never changes sign, the integrator does ramp —
  but only to its clamp (I term 1.00 after ~5 s), and on overshoot the P term
  dominates so windup never inverts the direction of travel. The anti-windup is
  correct. What is not safe about a stall is the full-duty hold, which is the
  separate entry above.
- **`kd = 0.05` was provably wrong and is now 0.** The encoder resolves 0.129°, so at
  the ~2 ms loop rate a single count reads as 64.6 deg/s — times `kd = 0.05` that is
  **3.23 of output**, past full duty from one tick of quantisation. Removing it cut
  direction reversals from ~260/s to ~12/s and time at full duty from 58% to 20%,
  and improved tracking as well. Reinstate only with a filtered derivative.
- **`kp = 0.8` remains aggressive.** It saturates for any error above 1.25°, so with
  the 1.0° deadband there is only a 0.25° sliver of proportional control. In
  simulation `kp = 0.30` tracked better (stance mean error 0.82° vs 2.33°), but the
  model has **no gravity or load torque**, which is exactly what `kp` fights — a
  softer gain could sag on the real robot. Left alone deliberately; tune on the bench.

Residual tracking error at 40 ms/step, `kp` 0.30 / `kd` 0 in simulation:

| | stance | swing |
|---|---|---|
| max | 7.85° | 9.40° |
| mean | 0.82° | 2.78° |

Stance mean of 0.82° is ~0.35 cm of foot error, which is fine. The maxima are at
liftoff and touchdown, where the target reverses direction; 9.4° is ~4 cm at the
foot, against **4.76 cm** of commanded swing clearance (not the nominal 5.0 —
see "Swing clearance is 4.76 cm" above) — so the margin is ~0.76 cm.
**Verify the foot actually clears the ground on the bench.** Easing the velocity through those corners would help more
than gain tuning.

### Minor: stale target for one tick
`pico_main.py` resets `current_step_index = 0` when a frame completes, but
`current_targets` isn't refreshed until the next `STEP_TICK_MS` tick (40ms) — so the
leg drives toward the *previous* frame's last target for up to 40ms. Also means step
0 of every buffer is skipped, since the first tick advances to index 1. The
recovery "go to neutral" move for the other three legs (a 2-entry one-shot buffer
holding `stand_pose` twice) relies on exactly this behavior to settle onto its
target within one tick — harmless there since both entries are identical, but worth
knowing this mechanism is now load-bearing elsewhere, not just a latent quirk.
`HOME_MARKER` is unaffected — it sets `current_targets` directly, bypassing the
buffer entirely.

---

## Verify on hardware

### RESOLVED — BNO085 constant names, and boot no longer dies on a bad hardware init

`imu.py` used `BNO08X.REPORT_LINEAR_ACCELERATION` / `...REPORT_ROTATION_VECTOR`.
Newer Adafruit library versions moved those to **module-level** names
(`BNO_REPORT_*`). Where the installed version has the module-level layout, the
old code raised `AttributeError` in the `IMU` constructor — and `main()` had no
guard, so **the robot would not boot at all.**

Two independent fixes:

1. **`imu.py` accepts either layout.** It now imports `BNO_REPORT_*` and falls
   back to `BNO08X.REPORT_*`, so which library version is installed stops
   mattering.

2. **Hardware init in `main()` is non-fatal.** IMU, GPS, compass, camera, power
   monitor and audio are each brought up through `_bring_up(name, factory, ...)`,
   which on failure logs the exception, marks that subsystem down, and returns
   `None`. `SensorHub` already tolerates a `None` sensor; `camera_loop` returns
   early with no camera; every `audio_engine.play()` is guarded. The robot boots
   **degraded** instead of not at all. The one exception is the Flask dashboard
   itself — without it you cannot home the legs — which still stops the boot, but
   only after announcing "FATAL: no dashboard" on the OLED.

The degraded state is surfaced:

- **On the dashboard:** the status array gained a 6-bit health mask at index 19
  (`imu, gps, compass, power, camera, audio`; behind `len >= 20`). The page
  shows an amber "Running degraded — camera did not start" banner, distinct from
  the red not-homed banner.
- **On an optional OLED:** `Code/Pi5/boot_display.py` drives a 1.3" SH1106 I2C
  panel — boot progress line by line ("IMU ... / IMU OK / Camera FAIL"), then the
  dashboard URL and the down-list once running. If `luma.oled` or the panel is
  absent every call is a no-op that echoes to stdout, so the error display can
  never itself become a boot blocker. Wiring and the one-line install are in
  `HARDWARE.md` at the repo root — it hangs on the existing I2C1 bus at 0x3C,
  no config change.

Still worth a bench check: that the BNO085 actually responds on `/dev/i2c-13`
and that the axis/sign conventions match (see the IMU-levelling entry above) —
but a wrong answer there now degrades to "IMU down, flat-footed walking", not a
dead boot.

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

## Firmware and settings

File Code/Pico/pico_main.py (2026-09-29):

import time
import struct 
from machine import UART, Pin
from fsr import FSR
from motor_control import JointController

# ==============================================================================
# LEG IDENTITY -- SET THIS BEFORE FLASHING. EVERY BOARD NEEDS A DIFFERENT VALUE.
# ==============================================================================
#   0 = Front Left     1 = Front Right     2 = Rear Right     3 = Rear Left
#
# The Pi reads this over UART at startup to learn which port drives which corner,
# so the UART wiring order stops mattering. But two boards sharing a value, or one
# set to the wrong corner, produces a wrong gait phase and the robot falls over.
# The Pi logs the map it detects -- check it before any powered walking.
LEG_ID = 0
# ==============================================================================

print("Imports successful")

# --- Setup Joints ---
roll_j  = JointController(rpwm_pin=3, lpwm_pin=2, en_pin=6, enc_a_pin=4, enc_b_pin=5, 
                          gear_ratio=99.5, ppr=28, reverse=False, initial_angle=0)
pitch_j = JointController(rpwm_pin=11, lpwm_pin=10, en_pin=7, enc_a_pin=8, enc_b_pin=9, 
                          gear_ratio=99.5, ppr=28, reverse=False, initial_angle=0)
knee_j  = JointController(rpwm_pin=15, lpwm_pin=14, en_pin=22, enc_a_pin=12, enc_b_pin=13, 
                          gear_ratio=99.5, ppr=28, reverse=False, initial_angle=0)
print("Joint Controllers setup successful")

# Which pin carries THIS leg's own foot sensor.
#
# This board drives one leg, and the abort test is "MY foot touched down while I
# should be airborne". It has to read one sensor. It used to read all four
# (FSR(16..19)) and collapse them with any(), which is wrong by construction: the
# crawl gait always has three feet planted, so any() is True for the whole of
# every swing phase and the leg aborted on its first step, every cycle. It never
# bit only because nothing is wired to these pins yet.
#
# Set this to the pin this leg's foot sensor is actually on before wiring them.
FSR_PIN = 16
foot = FSR(FSR_PIN)
print("FSR setup successful")

uart = UART(0, baudrate=115200, tx=Pin(0), rx=Pin(1), rxbuf=1024)
print("UART setup successful")
print("--------------------")

# --- Protocol ---
START_MARKER = b'\xAA\xAA'
HOME_MARKER = b'\xAB\xAB'           # web UI "Home this leg" command, no payload
RELAX_MARKER = b'\xAC\xAC'          # web UI "Stop" command, no payload
CYCLE_END_MARKER = b'\xFF' * 16     # gait: loop the buffer indefinitely
ONESHOT_END_MARKER = b'\xFE' * 16   # recovery: hold on the final step
PAYLOAD_SIZE = 16
ANGLE_LIMIT = 360.0
# Desync guard, not a design limit: an overlong frame means the stream lost
# sync mid-payload, and this stops the buffer growing until MemoryError.
# It MUST stay above every frame the Pi legitimately sends, and the biggest of
# those is the Stand/Go Cartesian ramp -- pi5_main.build_ramp(steps=40) emits
# steps+1 = 41 entries. This was 32, which silently threw the Stand and Go
# ramps away: the leg never left its homed pose and the robot could not stand.
# pi5_main.PICO_MAX_FRAMES mirrors this number and refuses to send past it.
MAX_GAIT_STEPS = 48

# Must match ik_and_gait.HOME_POSE on the Pi. Zeroing here only redefines what
# "current position" means -- it does not move the leg -- so this has to be the
# exact pose the leg was physically placed in by hand before homing.
HOME_POSE = (90.0, 0.0, 180.0)

# How often the step clock is re-aligned to a frame boundary.
#
# Every leg's end marker lands within a millisecond or two of the others, so
# resetting last_step_time there is a perfect cross-leg sync -- but it also
# throws away the partially-elapsed tick, and the Pi re-sends far more often
# than every 40 ms. Doing it on EVERY frame meant the tick never expired at all:
# measured 0 gait steps in 20 s for any re-send faster than 69 ms (29.3 ms of
# wire time + the 40 ms tick). The robot stood still while the Pi believed it
# was walking.
#
# So sync on a timer instead. Between syncs each board free-runs on its own
# crystal; at a worst-case 100 ppm spread that is 0.5 ms of drift over 5 s,
# against the 40 ms tick and the one-tick guard band between each leg's swing
# window. Cost is at most one truncated tick per 5 s, i.e. under 1% of walking
# speed.
RESYNC_INTERVAL_MS = 5000

# --- State Management ---
gait_buffer = []
# Frames land HERE while a new one is arriving, and are swapped into
# gait_buffer only once its end marker is parsed. gait_buffer used to be
# cleared at START_MARKER and refilled in place, which meant step 3 had nothing
# to play for the whole ~29.3 ms a frame takes on the wire -- so every steering
# or IMU update froze the gait for the duration, on top of the step-clock reset
# above. Staging lets the leg keep walking the previous cycle until the new one
# is complete, which is also what makes a desynced or truncated frame harmless.
rx_buffer = []
is_receiving = False
has_aborted = False
cycle_buffer = True
current_step_index = 0
# Length of the cyclic buffer that was playing when the current frame started
# arriving, or 0 if a one-shot was playing. Used to decide whether an incoming
# frame is a re-send of the same walking cycle (keep the phase) or something
# new (start at 0) -- see the end-marker handling.
prev_cycle_len = 0
# Web UI "Stop": no active holding torque, but the encoder ISR keeps counting
# regardless of this flag, so position (and homing) survives being unpowered.
# Resumes automatically the moment a real command arrives -- see HOME_MARKER
# and the end-of-frame handling below -- no separate "resume" command exists.
powered = True
# 40ms, not 20. At 20ms the gait demands 469 deg/s at the knee through liftoff and
# touchdown, against 360 deg/s free speed on the 5302 at 99.5:1 -- the PID saturates
# and the foot lands late. 40ms keeps the peak at ~235 deg/s (65% of free speed,
# leaving room for load) and costs walking speed: 16.7 cm/s instead of 33.3.
# Lower it only after checking on the bench that the legs still track their targets.
STEP_TICK_MS = 40
last_step_time = time.ticks_ms()
last_resync = time.ticks_ms()
prev_byte = b''

# --- Leg Identity Announcement ---
# Repeats until the Pi sends a first complete frame, so the Pi still learns the
# map when it boots after the Picos rather than before them.
ANNOUNCE_INTERVAL_MS = 500
identified = False
last_announce = time.ticks_ms()

# Holds at 0,0,0 -- wherever the leg physically is at power-on -- until either
# a HOME command or a gait frame arrives. move_to() drives toward this every
# loop regardless, so an unhomed leg just sits under light PID hold, not slack.
current_targets = [0.0, 0.0, 0.0]
# True while the zero-PWM branch is holding drive off, so PID state can be reset
# once on the transition back rather than every pass.
drive_was_cut = False

while True:
    # 1. READ UART (Binary Protocol Parser)
    # Drains everything buffered each pass; a single read per loop falls behind
    # the 16-byte-per-1.4ms arrival rate and overruns the RX buffer.
    while True:
        if not is_receiving:
            # Scan a byte at a time. Reading in 2-byte pairs can never recover
            # from an odd-byte misalignment, because the marker and the payload
            # are both even-length so the pairing parity never shifts.
            if not uart.any():
                break
            byte = uart.read(1)
            candidate = prev_byte + byte
            if candidate == START_MARKER:
                # Remember what was playing so the end-marker handler can tell a
                # re-send of the walking cycle from a genuinely new trajectory.
                prev_cycle_len = len(gait_buffer) if cycle_buffer else 0
                rx_buffer = []
                is_receiving = True
                has_aborted = False
                # A new frame is the Pi's answer to whatever went wrong, so give
                # the joints another go. If the jam is still physical they will
                # simply re-latch STALL_TIMEOUT_S later -- a retry every 1.5 s,
                # not a tight loop at full duty.
                roll_j.clear_stall()
                pitch_j.clear_stall()
                knee_j.clear_stall()
                prev_byte = b''
            elif candidate == HOME_MARKER:
                # Manual homing: the leg was positioned by hand, so "current
                # position" IS HOME_POSE now -- redefine the encoder zero to
                # match without commanding any motion, then hold there.
                roll_j.zero_at(HOME_POSE[0])
                pitch_j.zero_at(HOME_POSE[1])
                knee_j.zero_at(HOME_POSE[2])
                current_targets = list(HOME_POSE)
                gait_buffer = []
                rx_buffer = []
                is_receiving = False
                has_aborted = False
                powered = True   # a Home command means "now hold here"
                uart.write("HOMED,%d\n" % LEG_ID)
                prev_byte = b''
            elif candidate == RELAX_MARKER:
                # Stop: cut active holding torque. Deliberately does not touch
                # gait_buffer, current_targets or the encoder -- only step 4
                # below reads `powered`, so position tracking is untouched and
                # nothing needs re-homing once power resumes.
                powered = False
                prev_byte = b''
            else:
                prev_byte = byte
        else:
            if uart.any() < PAYLOAD_SIZE:
                break
            full_payload = uart.read(PAYLOAD_SIZE)

            if full_payload == CYCLE_END_MARKER or full_payload == ONESHOT_END_MARKER:
                cycle_buffer = full_payload == CYCLE_END_MARKER
                is_receiving = False
                # An empty frame keeps whatever was already playing rather than
                # leaving the leg with nothing to step through.
                same_cycle = (cycle_buffer and rx_buffer
                              and prev_cycle_len == len(rx_buffer))
                if rx_buffer:
                    gait_buffer = rx_buffer
                rx_buffer = []

                # KEEP THE PHASE across a re-send of the same walking cycle.
                # The Pi rebuilds and re-sends the whole gait whenever steering
                # or the IMU tilt changes, which is often. Restarting at index 0
                # every time teleports the foot from wherever it was in the
                # stroke to the start of swing -- measured worst case 25.6 deg
                # at a joint / 17.6 cm at the foot, and kp saturates above
                # 1.25 deg, so that is a full-duty slam several times a second.
                # Continuing at the same index leaves only the geometry
                # difference: 7.1 deg / 4.2 cm for a hard turn, and exactly zero
                # for an IMU-only nudge.
                #
                # Same length + both cyclic is the test for "this is the same
                # 20-step walking cycle, re-rendered". Anything else -- a
                # one-shot ramp, or a cycle of a different length -- starts at 0,
                # because a ramp genuinely has to run from its first entry.
                if same_cycle:
                    current_step_index = current_step_index % len(gait_buffer)
                    # Step clock deliberately left alone -- see
                    # RESYNC_INTERVAL_MS. Re-aligning here on every frame is
                    # what used to freeze the gait outright.
                    if time.ticks_diff(time.ticks_ms(), last_resync) > RESYNC_INTERVAL_MS:
                        last_step_time = time.ticks_ms()
                        last_resync = last_step_time
                else:
                    # A genuinely new trajectory (ramp, recovery, a cycle of a
                    # different length) starts at its first entry, and that IS
                    # the moment to re-align all four boards.
                    current_step_index = 0
                    last_step_time = time.ticks_ms()
                    last_resync = last_step_time
                prev_byte = b''
                identified = True   # the Pi is talking to us; stop announcing
                powered = True      # a real frame arrived -- go drive it
            else:
                try:
                    parts = list(struct.unpack('ffff', full_payload))
                except Exception:
                    parts = None
                # Drops non-finite and out-of-range angles, which a desynced
                # stream produces and which would otherwise reach the motors.
                if parts is not None and all(-ANGLE_LIMIT <= v <= ANGLE_LIMIT for v in parts[:3]):
                    rx_buffer.append(parts)
                    if len(rx_buffer) > MAX_GAIT_STEPS:
                        # Overlong frame means the stream desynced mid-payload and
                        # the terminator is being straddled. Abandon it and rescan
                        # rather than growing the buffer until MemoryError. Only
                        # the staged copy is thrown away, so the leg carries on
                        # walking the last good cycle instead of freezing.
                        rx_buffer = []
                        is_receiving = False
                        prev_byte = b''

    # 1b. ANNOUNCE LEG IDENTITY until the Pi starts sending us gait frames
    if not identified and time.ticks_diff(time.ticks_ms(), last_announce) > ANNOUNCE_INTERVAL_MS:
        uart.write("LEG,%d\n" % LEG_ID)
        last_announce = time.ticks_ms()

    # 2a. STALL CHECK (The Abort Logic, hardware-damage branch)
    # A joint whose PID has been pinned at full duty without closing its error
    # has met something it cannot move. JointController latches .stalled and has
    # already zeroed that joint's PWM; raise the same ABORTED path the FSR uses
    # so the Pi brings the whole robot to a safe pose instead of leaving three
    # legs walking. Without this the joint simply held 100% duty until something
    # burned out -- see ENGINEERING_NOTES.
    stalled_joint = None
    for name, j in (("roll", roll_j), ("pitch", pitch_j), ("knee", knee_j)):
        if j.stalled:
            stalled_joint = name
            break
    if stalled_joint is not None and not has_aborted:
        uart.write("STALL,%d,%s\n" % (LEG_ID, stalled_joint))
        msg = f"ABORTED,{roll_j.current_angle},{pitch_j.current_angle},{knee_j.current_angle}\n"
        uart.write(msg)
        has_aborted = True
        gait_buffer = []

    # 2b. GROUND CHECK (The Abort Logic)
    # This leg's own foot only -- see FSR_PIN.
    own_touchdown = foot.state

    # 3. CHOOSE TARGETS (every STEP_TICK_MS)
    # `is_receiving` is NOT a condition here any more: gait_buffer is the last
    # COMPLETE frame (an arriving one lands in rx_buffer), so the leg keeps
    # walking normally while the next frame is on the wire.
    if gait_buffer and not has_aborted:
        current_step_swing = gait_buffer[current_step_index][3] > 0.5
        if own_touchdown and current_step_swing:
            msg = f"ABORTED,{roll_j.current_angle},{pitch_j.current_angle},{knee_j.current_angle}\n"
            uart.write(msg)
            has_aborted = True
            gait_buffer = []
        else:
            elapsed = time.ticks_diff(time.ticks_ms(), last_step_time)
            if elapsed >= STEP_TICK_MS:
                # Advance by exactly one tick instead of resetting to now.
                # Resetting made the real cadence 40 ms PLUS however long the
                # pass took (~1-2 ms of loop, more while a frame is arriving),
                # so it tracked each board's own jitter -- tolerable while every
                # end marker re-synced the clock, but not now that a re-sync is
                # only every RESYNC_INTERVAL_MS. Fixed-step keeps the four legs
                # phase-locked to their crystals alone.
                if elapsed >= 2 * STEP_TICK_MS:
                    last_step_time = time.ticks_ms()      # fell behind; snap
                else:
                    last_step_time = time.ticks_add(last_step_time, STEP_TICK_MS)
                if cycle_buffer:
                    current_step_index = (current_step_index + 1) % len(gait_buffer)
                elif current_step_index < len(gait_buffer) - 1:
                    # One-shot trajectory (recovery): advance to the end, then hold.
                    current_step_index += 1
                current_targets = gait_buffer[current_step_index]

    # 4. EXECUTE CLOSED LOOP PID UPDATES
    # FIX: Run loop if we aren't aborted, regardless of incoming background updates.
    if has_aborted or not powered:
        # Same zero-PWM fallback for both cases: an abort is a fault latch that
        # needs recovery, "not powered" is the deliberate Stop command -- either
        # way the joint gets no drive current. The encoder ISR is independent of
        # this branch and keeps counting, so current_angle stays valid.
        roll_j.forward_pwm.duty_u16(0)
        roll_j.backward_pwm.duty_u16(0)
        pitch_j.forward_pwm.duty_u16(0)
        pitch_j.backward_pwm.duty_u16(0)
        knee_j.forward_pwm.duty_u16(0)
        knee_j.backward_pwm.duty_u16(0)
        drive_was_cut = True
    else:
        if drive_was_cut:
            # Drive has been off for an unknown length of time (a Stop can last
            # minutes). Without this the first move_to() sees a dt spanning the
            # whole gap and dumps error*dt into the integrator, saturating it in
            # one call. Same stale-dt failure the out-of-range guard already fixes.
            roll_j.reset_pid()
            pitch_j.reset_pid()
            knee_j.reset_pid()
            drive_was_cut = False
        roll_j.move_to(current_targets[0])
        pitch_j.move_to(current_targets[1])
        knee_j.move_to(current_targets[2])

    time.sleep_ms(1)

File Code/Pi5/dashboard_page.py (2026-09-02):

"""
dashboard_page.py -- the APEX Mission Control web page markup, in one place.

Pure string. No imports, no ROS, no hardware -- so both stream_server.py (the
real dashboard) and dashboard_preview.py (the throwaway UI mock) render the
*same* page and cannot drift apart.

render() takes only what the server knows at request time. The page's live
state comes from polling /status, exactly as before.

Layout, top to bottom: APEX wordmark + status pills -> video feed -> steering
-> startup (home/stand/go) -> obstacle avoidance -> debug. The wordy
explanations are tucked behind a small "i" button on each card heading
(toggleInfo), off by default.

Styling: Bootstrap 5 for the reset, typography, grid and spacing utilities,
with the APEX red/black theme layered on top in the inline <style>. Bootstrap
is served from the robot, not a CDN -- Code/Pi5/static/bootstrap.min.css, which
Flask publishes at /static/ automatically because both servers construct their
app as Flask(__name__) from this directory. Nothing on this page reaches the
internet, so it renders identically with the Pi acting as its own access point
in the field.

The theme is also deliberately self-sufficient -- colours, cards, buttons and
the button rows are all defined here with plain flexbox -- so even if
static/bootstrap.min.css goes missing the page still lays out and reads
correctly, it just loses Bootstrap's polish.

Colour semantics: red = engaged / live, dark grey = idle, amber = degraded.
"""

# Tokens, not f-string / .format() / Template: the page is full of literal { }
# in its CSS and JavaScript, and a plain replace() sidesteps every escaping
# question. Note also that no two braces may end up adjacent in the rendered
# output ("{{" / "}}") -- the verification script treats that as an escaping
# bug -- so nested CSS/JS blocks always close on separate lines.
_PAGE = """
<html lang="en">
<head>
    <meta charset="utf-8">
    <title>APEX Mission Control</title>
    <meta name="viewport" content="width=device-width, initial-scale=1">
    <link href="/static/bootstrap.min.css" rel="stylesheet">
    <style>
        :root {
            --apex-bg:      #08080a;
            --apex-panel:   #141417;
            --apex-panel-2: #0f0f12;
            --apex-line:    #2a2a31;
            --apex-red:     #e01020;
            --apex-red-hi:  #ff2a3a;
            --apex-text:    #e9e9ec;
            --apex-muted:   #8b8b95;
            --apex-amber:   #f0a020;
        }
        html, body { height: 100%; }
        body {
            background:
                radial-gradient(1100px 520px at 50% -160px, rgba(224,16,32,.18), transparent 70%),
                var(--apex-bg);
            background-attachment: fixed;
            color: var(--apex-text);
            font-family: "Segoe UI", Roboto, Helvetica, Arial, sans-serif;
            text-align: center;
            padding-bottom: 2.5rem;
        }

        /* ---- header / wordmark ------------------------------------------ */
        .apex-header { padding: 1.6rem 1rem .4rem; }
        .apex-brand {
            font-size: clamp(2.6rem, 12vw, 5.4rem);
            font-weight: 900;
            line-height: 1;
            letter-spacing: .32em;
            text-indent: .32em;   /* cancels the trailing letter-space, keeps it centred */
            color: #fff;
            text-shadow: 0 0 18px rgba(224,16,32,.60), 0 0 52px rgba(224,16,32,.28);
        }
        .apex-tag {
            margin-top: .55rem;
            font-size: .72rem;
            font-weight: 600;
            letter-spacing: .42em;
            text-indent: .42em;
            color: var(--apex-muted);
        }
        .apex-rule {
            height: 3px; width: min(520px, 88%); margin: .9rem auto 0; border-radius: 2px;
            background: linear-gradient(90deg, transparent, var(--apex-red) 18%,
                        var(--apex-red-hi) 50%, var(--apex-red) 82%, transparent);
        }

        /* ---- status pills ------------------------------------------------ */
        .pills { display:flex; flex-wrap:wrap; gap:.5rem; justify-content:center;
                 margin: 1rem auto 0; }
        .pill {
            font-size: .68rem; font-weight: 700; letter-spacing: .14em;
            padding: .34rem .8rem; border-radius: 999px;
            border: 1px solid var(--apex-line); background: #131316;
            color: var(--apex-muted); font-family: ui-monospace, Consolas, monospace;
        }
        .pill.live {
            background: linear-gradient(180deg, var(--apex-red-hi), var(--apex-red));
            border-color: #ff4b57; color: #fff;
            box-shadow: 0 0 14px rgba(224,16,32,.45);
        }
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

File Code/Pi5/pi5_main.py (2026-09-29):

import threading
import math
import time
import serial
import struct
import rclpy
from rclpy.node import Node
from rclpy.executors import MultiThreadedExecutor
from std_msgs.msg import Float32MultiArray, Int32, Int32MultiArray, Bool
import os

WAV_DIR = os.path.dirname(os.path.abspath(__file__))

# Core hardware and engine imports
from power_monitor import INA219
from inverse_kinematics.ik_and_gait import (
    InverseKinematics, GaitPath, GaitIK, RecoveryPath,
    LEG_FL, LEG_FR, LEG_RR, LEG_RL, LEG_ORDER, LEG_NAMES,
    HIP_POSITIONS, LEG_SIGN_X, LEG_SIGN_Y,
    phase_offsets, HOME_POSE, cartesian_ramp, body_twist_xy_path,
    body_shift_profile, apply_body_shift, attitude_height_offsets,
)
from audio import QuadrupedAudio
from webcam import USBWebcam
from stream_server import RobodogStreamer
from navigation import GPSReader, CompassReader, Navigator
from imu import IMU
from sensor_hub import SensorHub
from boot_display import BootDisplay

# Vision-based obstacle avoidance is optional and guarded: it pulls in
# onnxruntime and a ~100MB model file, neither of which is needed to walk. A
# missing or broken install has to degrade to "no avoidance", never to a robot
# that will not boot.
try:
    from vision_obstacle import ObstacleAvoider, AvoidState
except Exception as _vision_err:
    ObstacleAvoider, AvoidState = None, None
    print(f"[VISION] obstacle avoidance unavailable: {_vision_err}")

class RobotMode:
    """What the operator asked for. Only nav_mode_callback writes this."""
    MANUAL = 0
    AUTONOMOUS = 1


class RobotActivity:
    """What the robot is doing right now. Only the recovery path writes this.

    Split out of the old single `current_state` field, which used one variable
    for both meanings. That caused a real hazard: nav_mode_callback overwrote
    it unconditionally from a ROS executor thread, so a NAV toggle landing
    between handle_recovery() staging a recovery and _gait_serial_worker
    reading it made the worker's `== RECOVERY` test fail. The recovery was then
    never transmitted and the aborted leg stayed frozen at zero PWM with
    has_aborted latched, while the other three kept walking -- i.e. the robot
    falls. It also meant every recovery silently reset the mode to MANUAL,
    dropping the robot out of GPS nav while the dashboard still read NAV: ON.
    """
    NORMAL = 0
    RECOVERY = 1


# Back-compat alias: RobotState.MANUAL / .AUTONOMOUS still resolve for anything
# that imports them. RECOVERY deliberately does NOT exist here any more, so a
# stale reference fails loudly instead of silently comparing against a mode.
RobotState = RobotMode

# Leg identity, body geometry and mounting all live in ik_and_gait.py so that
# pi5_main and quadruped_sim cannot drift apart. build_gait() lays the second
# axis out in LEG_ORDER and _gait_serial_worker indexes it by leg id, which only
# lines up while LEG_ORDER is sorted.
assert LEG_ORDER == tuple(range(len(LEG_ORDER))), "LEG_ORDER must stay in leg-id order"

# Portion of the cycle a foot spends airborne. 0.25 keeps three feet planted at
# all times, which is what the [0, N/2, 3N/4, N/4] crawl sequencing needs.
SWING_FRACTION = 0.25
GAIT_STEPS = 20
STAND_HEIGHT = 36.0
SWING_HEIGHT = 5.0

# Must match Pico/pico_main.py STEP_TICK_MS -- used to time the startup ramp.
STEP_TICK_S = 0.040

# Floor on how often the control loop may push a rebuilt gait to the legs.
#
# A frame is 2 + 20*16 + 16 = 338 bytes; at 115200 8N1 that is 29.3 ms of wire
# time per port. The resend trigger (steering moved >5 deg, tilt >1.5 deg,
# stride >0.05) is evaluated every ~10 ms and nothing rate-limited it, so a
# turn or a bit of uneven ground could queue frames faster than the wire could
# carry them. Two failures, both measured in scratchpad/wire_timing.py:
#
#   * under ~30 ms the worker starts the next frame while the previous is still
#     draining, and its reset_output_buffer() (POSIX tcflush) DISCARDS the tail
#     -- including the end marker, which leaves the Pico stuck in is_receiving;
#   * under ~69 ms (29.3 wire + 40 tick) the old firmware never advanced a
#     single gait step, because it reset its step clock on every end marker:
#     0 steps in 20 s, i.e. the robot stands still while the dashboard says
#     WALKING.
#
# 100 ms keeps steering latency at 10 Hz -- 1.7 cm of travel at 16.7 cm/s -- and
# leaves 3.4x margin over the wire time. The Pico-side staging fix removes the
# 69 ms floor as well, but this stays as the wire-level backstop and so that
# newer Pi code against un-reflashed firmware degrades rather than freezes.
MIN_GAIT_RESEND_S = 0.10

# Must match Pico/pico_main.py MAX_GAIT_STEPS. The Pico treats an overlong frame
# as a desynced stream and throws the whole thing away, so a frame that exceeds
# this does not degrade -- it silently does nothing. send_entire_gait() refuses
# to transmit past it rather than letting that happen unnoticed. The largest
# legitimate frame is the Stand/Go ramp at RAMP_STEPS + 1.
PICO_MAX_FRAMES = 48
# Cartesian ramp resolution for Stand and Go. steps+1 entries are sent.
RAMP_STEPS = 40

# Zero, not 2.5. Three feet are planted at different points in the stance phase,
# so any downward push commands them to depths spanning ~2.2 cm -- on flat rigid
# ground they cannot all be there, and it becomes body bob or lost contact.
# Raise it only alongside closed-loop FSR contact for uneven terrain.
STANCE_PUSH = 0.0

# How far the body leans toward the supporting tripod before each lift. Without
# it the centre of mass rides the support triangle's edge with ~4 mm of margin;
# 2 cm takes that to ~2.2 cm. Costs foot workspace, so do not inflate it.
BODY_SHIFT_CM = 2.0
# During a turn the feet arc off their nominal positions, which the 2 cm lean no
# longer covers -- quadruped_sim --report shows the margin falling to +0.7 cm at
# a full spin. Ramping the lean to 4 cm as the turn tightens restores it to
# +2.6 cm, and the reduced forward stride keeps the joint rate in bounds (79%).
# Straight walking (yaw 0) is untouched -- it still uses BODY_SHIFT_CM exactly.
TURN_BODY_SHIFT_CM = 4.0

# IMU levelling. gain 1.0 would fully cancel the measured tilt in one update,
# which invites overshoot; 0.6 damps it. The limit caps how far one corner can
# be driven from the nominal stand height.
ATTITUDE_GAIN = 0.6
ATTITUDE_LIMIT_CM = 4.0
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

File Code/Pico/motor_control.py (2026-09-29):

import time
from machine import Pin, PWM

# --- Configuration ---
EXTERNAL_GEAR_REDUCTION = 1
MIN_STALL_POWER = 0.15

# --- Stall detection ---------------------------------------------------------
# kp = 0.8 saturates the output for any error above 1.25 deg, so a joint that
# meets something it cannot move sits at 100% duty with nothing to bring it back
# down -- no current limit, no thermal cutout. Held, that cooks the motor or the
# BTS7960. This is the software backstop until the BTS7960 IS current-sense pins
# are wired (see ENGINEERING_NOTES).
#
# The discriminator is PROGRESS, not duty: a normal large move also saturates,
# but it closes its error fast. The gait's worst legitimate case is the Stand/Go
# ramp, whose steps are small, and a full 90 deg swing at the measured 266 deg/s
# still completes in ~0.34 s. 1.5 s of full duty with the error refusing to fall
# by STALL_PROGRESS_DEG is not a move in progress -- it is a jam.
STALL_TIMEOUT_S = 1.5
STALL_PROGRESS_DEG = 2.0

# Quadrature transition table: index = (prev_state << 2) | new_state
# where state = (A << 1) | B. Valid single-step transitions only;
# invalid/skipped transitions (missed edges) map to 0 (ignored) rather
# than corrupting the count.
_QUAD_TABLE = {
    0b0001: 1, 0b0111: 1, 0b1110: 1, 0b1000: 1,
    0b0010: -1, 0b1011: -1, 0b1101: -1, 0b0100: -1,
}

class JointController:
    def __init__(self, rpwm_pin, lpwm_pin, en_pin, enc_a_pin, enc_b_pin, gear_ratio, ppr, reverse, initial_angle):
        """
        gear_ratio: 99.5 (from specs)
        ppr: 28 (from specs, full quadrature decoded)
        """
        # --- Hardware Setup ---
        self.en = Pin(en_pin, Pin.OUT)
        self.reverse = reverse

        self.forward_pwm = PWM(Pin(rpwm_pin))
        self.backward_pwm = PWM(Pin(lpwm_pin))
        self.forward_pwm.freq(1000)   # Dropped to 1000Hz for optocoupler stability
        self.backward_pwm.freq(1000)  # Dropped to 1000Hz for optocoupler stability
        
        self.en.value(1) # Turn on the H-Bridge
        
        # --- Dynamic Math using your Specs ---
        ticks_per_joint_rev = ppr * gear_ratio * EXTERNAL_GEAR_REDUCTION
        self.ticks_per_degree = ticks_per_joint_rev / 360.0

        # --- Encoder Setup (full quadrature: both edges, both channels) ---
        self.enc_a = Pin(enc_a_pin, Pin.IN)
        self.enc_b = Pin(enc_b_pin, Pin.IN)
        self._last_state = (self.enc_a.value() << 1) | self.enc_b.value()
        
        # FIX 1: If hardware is reversed, our initial starting position pulses must be inverted
        raw_initial_steps = int(initial_angle * self.ticks_per_degree)
        self._steps = -raw_initial_steps if self.reverse else raw_initial_steps
        
        self.enc_a.irq(trigger=Pin.IRQ_RISING | Pin.IRQ_FALLING, handler=self._encoder_isr)
        self.enc_b.irq(trigger=Pin.IRQ_RISING | Pin.IRQ_FALLING, handler=self._encoder_isr)

        # --- PID Tuning for goBILDA ---
        self.kp = 0.8
        self.ki = 0.02
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

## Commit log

2026-05-24 More naming convention fixes and bug fixes
    [single_leg_test.py]
2026-05-25 Add renderings of CAD
2026-05-27 Stop tracking power_shutoff_wiring.txt
2026-06-23 Add scripts to normalize Fusion PCB production files
    [Fixed_PCB_V1_BOM.csv, PCB_V1_BOM.csv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]
2026-06-23 Remove old production files
    [Fixed_PCB_V1_BOM.csv, PCB_V1_BOM.csv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]
2026-08-28 Add Obstacle Avoidance using Depth Tracking and CV
    [pi5_main.py, stream_server.py, vision_obstacle.py]
2026-09-02 Minor Update
    [APEX Leg V2.2.f3z, APEX.f3z, PCB V1.f3z]
2026-09-02 Add Pi 5 requirements.txt
    Groups runtime deps by function; obstacle avoidance (onnxruntime/numpy)
    and the boot OLED (luma.oled) are marked optional. ROS 2 and i2c-tools
    noted as separate apt installs. README now points here instead of listing
    pip lines inline.
2026-09-02 Refuse NAV MODE and Start until a route is loaded
    Flipping NAV MODE with no waypoints used to switch the robot to AUTONOMOUS
    and march in place, which reads as a broken toggle. Now blocked at three
    layers:
    - dashboard greys the NAV MODE toggle and Start button when wp_total == 0
    - stream_server toggle_nav / nav_control return 409 without publishing
    - nav_mode_callback / nav_cmd_callback bail on _route_loaded(), so a
    replayed or direct topic publish can't bypass the UI check
    dashboard_preview mirrors the same refusals. wp_e2e covers the no-route
    path at every layer.
    [dashboard_page.py, dashboard_preview.py, pi5_main.py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]
2026-09-02 Compass: true-north declination, tilt compensation, failure handling
    - CompassReader(declination_deg): MAGNETIC_DECLINATION_DEG (-13 for
    northern NJ) added to every heading so it matches true-north GPS
    bearings and Google Maps coordinates
    - get_heading(roll_deg, pitch_deg): AN3192 tilt compensation fed the
    live IMU attitude by SensorHub; exact no-op at roll=pitch=0 so level
    behaviour is unchanged
    - returns None (not 0.0 / not garbage) on I2C OSError, the QMC5883L
    overflow bit, and all-0x0000 / all-0xFFFF blocks; soft-reset on init
    - SensorHub tracks heading_age (time since last *good* read; the shared
    nav poller keeps ticking on GPS so a held heading can't reveal a dead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
    [dashboard_page.py, navigation.py, pi5_main.py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]
2026-09-03 Stop autonomous nav driving on a dead GPS / camera; lock port_by_leg
    Same failure shape as the compass frozen-heading bug, three more places:
    - GPSReader.fix_t timestamps the last positional GGA; nav_snapshot()
    exposes fix_age. A receiver that goes quiet (fix > GPS_FIX_MAX_AGE_S
    = 5 s) counts as no-fix even with has_fix latched True.
    - the "no usable GPS fix" branch in the control loop only printed --
    chosen_direction / stride_scale fell through carrying the last MANUAL
    steering value at full stride, so a robot that lost its fix mid-
    mission walked off blindly. Now holds position like the other
    degraded branches.
    - subsystem_health for gps/compass is updated live from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
    [navigation.py, pi5_main.py, sensor_hub.py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]
2026-09-04 INA219: voltage-only, current path parked until wiring is confirmed
    It's unconfirmed whether a shunt is actually in the load path on the
    board, so the current/power readings may be meaningless.
    - sensor_hub._power_poll reads voltage only; stores current = None
    - pi5_main power check is now `voltage < LOW_VOLT_THRESHOLD` alone
    (dropped the c > MAX_CURRENT_MA half and the unused constant)
    - INA219.get_current()/get_power() kept intact but uncalled, with
    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
2026-09-05 Bring README up to date with the INA219 and dashboard changes
    Voltage-only INA219 status (BOM, file tree, and a Control Loop
    paragraph pointing at KNOWN_ISSUES for the two open bench checks),
    requirements.txt added to the Pi5 file tree, and the Google Maps
    lat/lng paste convenience noted under the Navigation card.
2026-09-05 KNOWN_ISSUES: disambiguate the two "current sensing" items
    The FSR-migration entry claimed the INA219 "reads total pack current" —
    stale since it is read for voltage only now. Also renamed an "FSR"
    meaning full-scale range in the INA219 entry, which collided with the
    force-sensitive-resistor sense used everywhere else in the doc.
2026-09-05 KNOWN_ISSUES: top-of-file note to build BTS7960 per-motor current sensing
    Crash/blockage detection off each BTS7960's built-in IS current-sense
    output, feeding handle_recovery when a joint meets resistance it
    shouldn't have. Not implemented; no code exists for it yet.
    Also corrects the FSR-migration section, which claimed the per-joint
    sense hardware "doesn't exist yet" -- the current mirror is already in
    the driver chip, and GP26/27/28 (ADC0/1/2) are free on every Pico,
    exactly one per joint, so each board reads only its own three motors.
2026-09-05 KNOWN_ISSUES: trim the current-sensing callout, revert 82f1337
    Shortens the top TO BUILD note to just what it is and why, dropping the
    wiring specifics and the INA219 comparison from the callout itself (the
    GP26/27/28 detail still lives in the PLANNED section below).
    Also reverts 82f1337, which was unrequested and based on a misreading of
    which "current sensing" was meant: restores the INA219 sentence in the
    FSR-migration bullet and puts the "±3.2 A FSR" wording back.
2026-09-05 Full-repo audit: document the stall hazard and the FSR abort bug
    Findings from reading the whole control path. Two are hazards that were
    not written down anywhere:
    - A blocked joint holds 100% PWM indefinitely. Anti-windup is correct
    (integral clamps at 50, I term maxes at 1.00, and P dominates so it
    never inverts direction on overshoot) -- the problem is kp=0.8
    saturating the output above 1.25 deg of error with no stall timeout,
    current limit or thermal cutout to bring it back down. Measured
    against the real JointController.
    - pico_main's FSR abort is any() across all four foot sensors ANDed
    with this leg's swing flag. A crawl gait always has three feet
    planted, so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
    [single_leg_test.py, vision_obstacle.py]
2026-09-05 Fix the audit findings: stall guard, FSR abort, PID reset, broken files
    Needs a Pico reflash -- four of the five are firmware.
    - Stall guard. JointController latches .stalled when the pre-clamp output
    has been saturated for STALL_TIMEOUT_S (1.5 s) while |error| refuses to
    fall by STALL_PROGRESS_DEG (2 deg), zeroes both PWMs, and stays latched
    until clear_stall()/zero_at(). pico_main polls the three joints and
    raises the existing ABORTED path so the Pi runs its normal recovery.
    Progress, not duty, is the discriminator, so a legitimate large move
    does not trip it. Verified against a motor model: latches at 1.50 s on
    a jam; clean through a 90 deg move, 10 s of gait, and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
    [fsr.py, motor_control.py, pico_main.py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]
2026-09-09 Fix two defects that stopped the robot walking, plus stall-guard hardening
    Third full-repo audit. Two of these are showstoppers that would have shown up
    on the first powered walk.
    Receiving a gait frame froze the gait. A frame is 338 bytes = 29.3 ms of wire
    time, and the Pico both cleared gait_buffer at START_MARKER (so step 3 had
    nothing to play while it arrived) and reset last_step_time on every end marker
    (restarting the 40 ms tick each time). Nothing rate-limited the Pi's re-send
    trigger, which is evaluated every ~10 ms. Measured against the real parser
    logic and real baud timing: 0 gait steps in 20 s for any re-send faster than
    69 ms, i.e. the robot stands still while the dash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
    [motor_control.py, pi5_main.py, pico_main.py]
2026-09-09 KNOWN_ISSUES: list the unverified IMU roll/pitch signs as an open issue
    It was only a bench-check line under "Before you walk it". It is a real open
    defect with a divergent failure mode, so it now has its own OPEN entry under
    "Will make the robot fall over" with the numbers (8.6 deg of self-inflicted lean
    at ATTITUDE_LIMIT_CM against a +2.38 cm stability margin), why the simulator
    cannot catch it, and the bench procedure. Also surfaced in the top banner; the
    checklist entry is now a pointer so the two cannot drift.
2026-09-09 IK: drop the fictional outlier-filter seed, and verify the knee cannot branch-flip
    GaitIK.get_gait_ik() rejects a >90 deg roll discontinuity between adjacent steps
    by reusing the previous value, but seeded that previous value with 0.0 for step
    0 -- a pose the leg is never in (measured range across the envelope: -27.1 to
    -6.3 deg). The step-0 comparison was therefore against a fiction, and had it
    ever fired it would have SUBSTITUTED 0.0, i.e. the guard issuing a bad command
    rather than blocking one, silently. Seed with None instead: step 0 is simply
    unguarded, which is correct because there is nothing to compare it against.
    No output changes -- the guard has never fired anywhere.
    Al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
2026-09-09 KNOWN_ISSUES: record the gait-quality measurements (propulsion, roll recruitment)
    Separate question from stability, so measured separately.
    Straight: one leg airborne max, four four-down beats, lift order FL->RR->FR->RL.
    Hip pitch sweeps 16.41 deg monotonically per stance on every leg and all four
    feet travel -10.00 cm fore/aft -- the commanded stride exactly, so propulsion is
    shared. Zero ticks with planted feet opposing; worst disagreement 0.100 mm, which
    is the round(x,2) quantisation, not scrub.
    Turning: hip roll is the only joint that moves a foot sideways, so it is measured
    over stance only (x and z constant there). Sweep goes 0.0000 deg straight ->
    3.09 -> 6.28 -> 9.33 deg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
2026-09-15 Untrack CAD/cpl_fixer.py and CAD/bom_fixer.py
    Keep them locally but stop syncing to the cloud repo.
2026-09-20 Rename KNOWN_ISSUES.md to ENGINEERING_NOTES.md
    The file is a mix of resolved-defect history, open issues, pre-flight
    checklists, and reference notes -- "known issues" undersold most of
    that. Update every code comment and README pointer to match.
    Also record the single-preloaded-UF2 deployment idea discussed today:
    a short pointer in "Read this first" and a full PLANNED section
    detailing how it would work (UF2 block concatenation against a
    prebuilt littlefs filesystem image) and why it's parked for now (the
    image would be pinned to one MicroPython firmware version, and every
    board still needs per-leg hand-editing regardless).
    [motor_control.py, pi5_main.py, pico_main.py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]
2026-09-30 Update CAD files
    [APEX Leg V2.2.f3z, APEX.f3z, PCB V1.f3z]
2026-10-12 Replace FSR foot contact with motor current sensing and some other small fixes
2026-10-12 Replace FSR foot contact with motor current sensing and some other small changes
2026-10-31 Updated CAD Files
2026-11-07 Add a route to the Flask server for serving sensor data
